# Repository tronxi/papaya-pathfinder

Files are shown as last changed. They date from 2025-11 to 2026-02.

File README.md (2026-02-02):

# Papaya Pathfinder

<div style="text-align: center;">
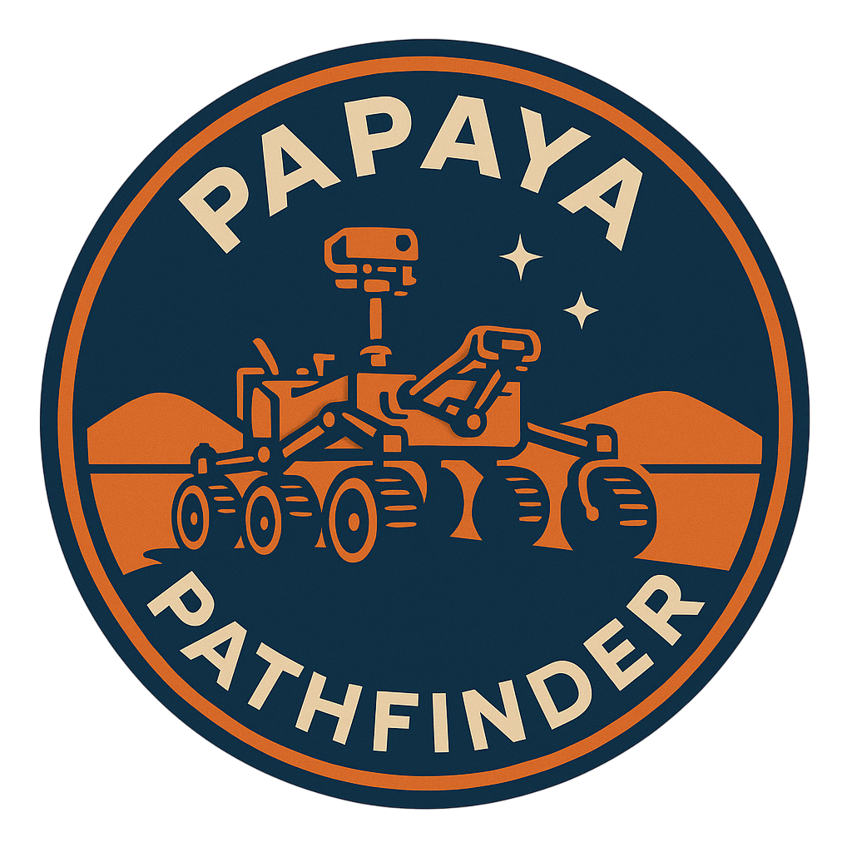
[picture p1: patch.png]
Papaya Pathfinder patch
  
</div>

Papaya Pathfinder is an open-source family of small remote-controlled rovers based on the **ESP32**.

The project currently includes **two rover variants**, designed for different sizes, motors, and power requirements.

All mechanical parts of the rovers are fully **3D-printable**, and all models are available in the `3d-models/` directories of each rover variant.

The rovers can be operated using either **WiFi** or **ExpressLRS (ELRS)**, depending on the firmware configuration.

**Watch the Papaya Pathfinder demo on YouTube**
<div align="center">
  <a href="https://www.youtube.com/watch?v=BrZb676o0gw" target="_blank">
    Papaya Pathfinder - Demo Video
  </a>
</div>

## Papaya Pathfinder

- **Controller:** ESP32
- **Radio:** ELRS receiver *(required only when running `firmware-elrs`)*
- **Motor Drivers:** 2× BTS7960 43A (or similar high-current driver)
- **Motors:** 6× GA25 DC gear motors
- **Steering:** 4× MS24 servos
- **Power:** LiPo 3S Battery
- **Voltage Regulation:**
  - 1× UBEC 5V/3A (for ESP32)
  - 1× UBEC 6V/8A (High current supply for Servos)

### Firmware
The rover supports multiple firmware configurations, each enabling a different communication method.

- **[`firmware-wifi`](pathfinder/firmware-wifi/)**
  - WiFi-based control
  - HTTP API for movement commands
  - Compatible controllers:
    - **[Python desktop controller](desktop-controller/)** — sends gamepad-based control commands to the rover via HTTP.
    - **[Android mobile app](android-controller/)** — enables rover control using a gamepad, providing the same driving experience available on the desktop controller.

- **[`firmware-elrs`](pathfinder/firmware-elrs/)**
  - Control via **ExpressLRS (ELRS)**

### 3D-Printed Parts

<div style="text-align: center;">
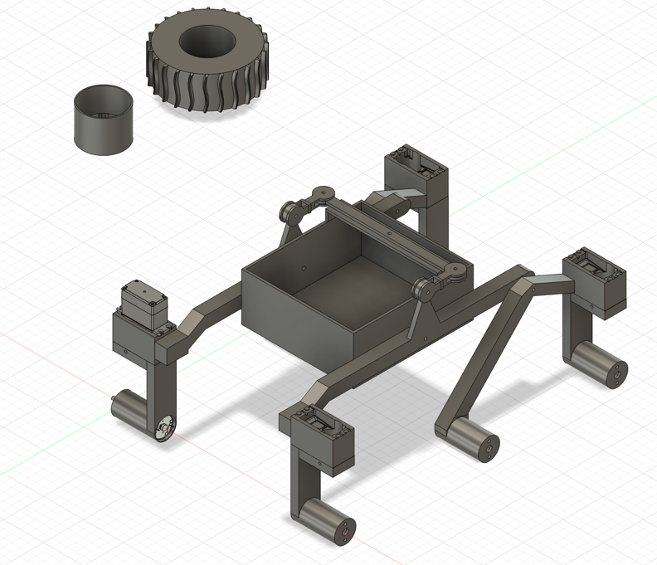
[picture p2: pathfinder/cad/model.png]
Papaya Pathfinder model
  
</div>

All STL files for this rover are available in: **[`pathfinder/3d-models/`](pathfinder/3d-models/)**

The complete mechanical design is also available in **STEP format**: **[`pathfinder/cad/papaya-pathfinder.step`](pathfinder/cad/papaya-pathfinder.step)**

Use **PETG or PLA** for the structural parts, and **TPU** for the tires. All parts are designed to be assembled using **M3 screws and nuts**.

| File | Qty | Material | Notes |
|---|-----|---|---|
| `body.stl` | 1 | PETG / PLA | Main chassis |
| `arm_left.stl` | 1 | PETG / PLA | Left suspension arm |
| `arm_right.stl` | 1 | PETG / PLA | Right suspension arm |
| `pivot_left.stl` | 1 | PETG / PLA | Left pivot mount |
| `pivot_right.stl` | 1 | PETG / PLA | Right pivot mount |
| `differential_bar.stl` | 1 | PETG / PLA | Central rocker-bogie differential bar |
| `differential_link_left.stl` | 1 | PETG / PLA | Left link between differential bar and suspension arm  |
| `differential_link_right.stl` | 1 | PETG / PLA | Right link between differential bar and suspension arm |
| `motor_mount.stl` | 4 | PETG / PLA | Motor mounts for GA25 motors used on steering arms |
| `horn_adapter.stl`  | 4 | PETG / PLA | Servo horn adapters for steering servos. **Print horizontally for strength.** |
| `rim.stl` | 6 | PETG / PLA | **Standard option.** Connects directly to the motor shaft (D-shape). Simple, but can strip over time under high torque. |
| `rim_hexagonal.stl` | 6 | PETG / PLA | **Pro option (Recommended).** Requires **12mm brass hex adapters**. Much stronger connection, prevents the motor shaft from stripping the plastic. |
| `tire.stl` | 6 | TPU | Tires |

### Wiring Diagram
- Power Distribution: Shows the rover power distribution, including the LiPo 3S battery,
  separate UBECs for logic (5V) and servos (6V), and the motor power rails.
<div style="text-align: center;">
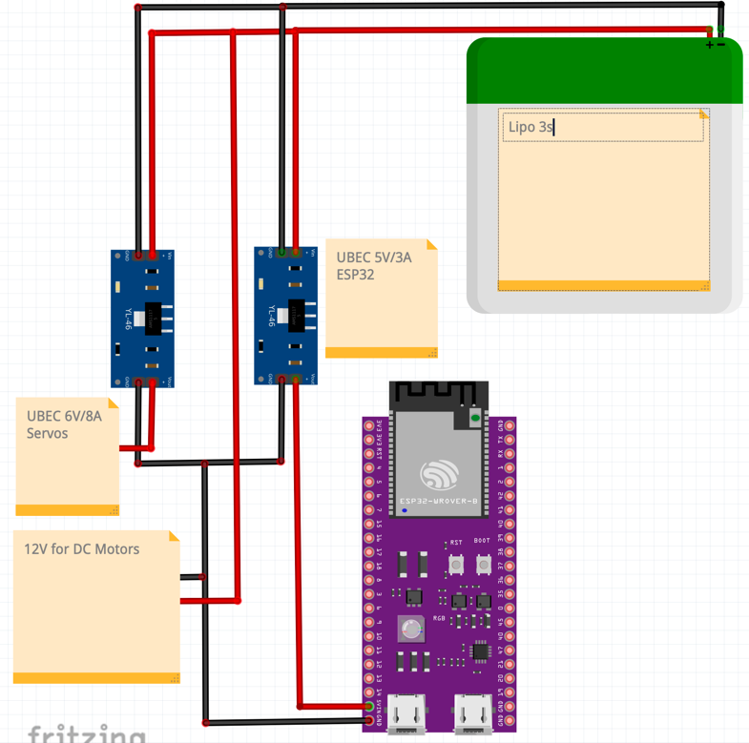
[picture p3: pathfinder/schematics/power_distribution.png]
Papaya Pathfinder power distribution
  
</div>

- Motors: Motor wiring using two BTS7960 drivers, each controlling one side of the rover.
  The ESP32 provides PWM control signals to each driver.
<div style="text-align: center;">
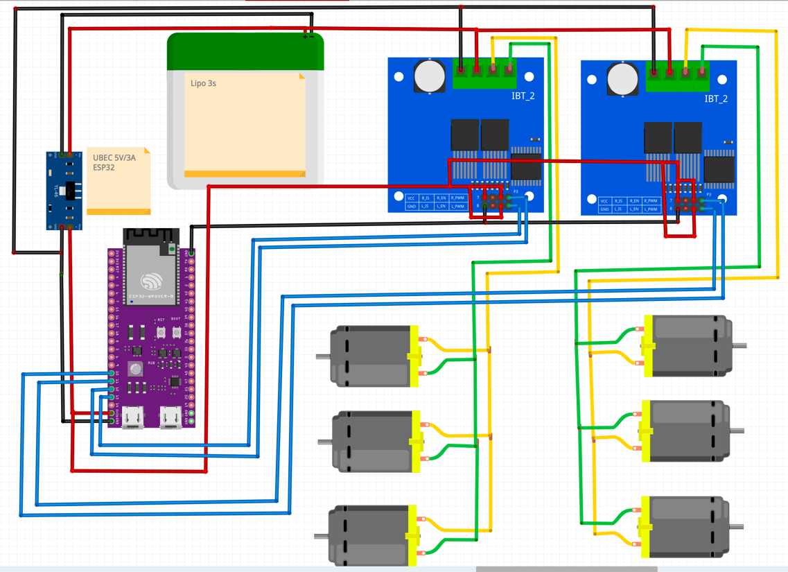
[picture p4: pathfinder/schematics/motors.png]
Papaya Pathfinder motors
  
</div>

- Servos: Servo wiring powered by a dedicated 6V UBEC. PWM control signals are provided by the ESP32.
<div style="text-align: center;">
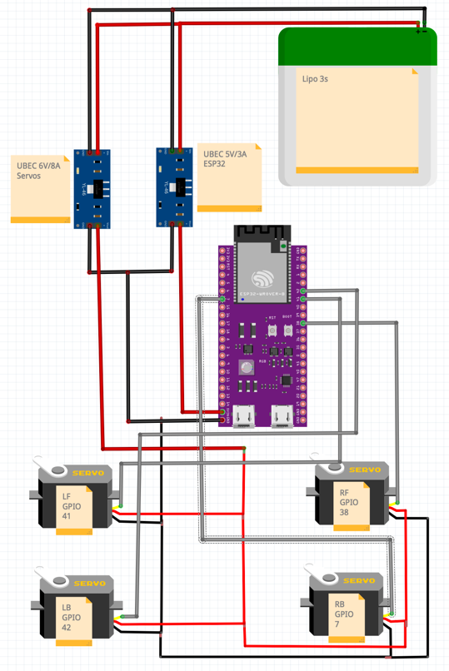
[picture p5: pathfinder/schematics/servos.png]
Papaya Pathfinder servos
  
</div>

- System Overview: High-level overview of the complete rover wiring, combining power,
  motor drivers, servos and control logic.
<div style="text-align: center;">
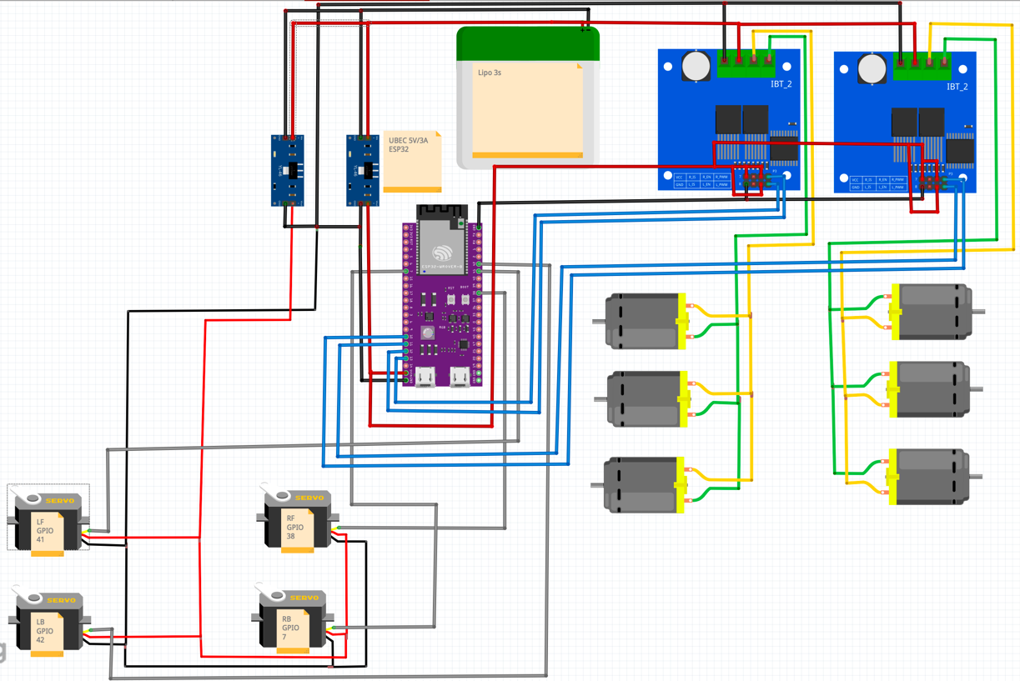
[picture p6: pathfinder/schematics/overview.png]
Papaya Pathfinder overview
  
</div>

---

## Papaya Pathfinder Mini

- **ESP32 with camera (ESP32-CAM / ESP32-S3-CAM)** *(required only when running `firmware-wifi`)*
- **ELRS receiver** *(required only when running `firmware-elrs`)*
- **6× N20 DC gear motors**
- **Power supply: LiPo 2S**
- **Voltage regulation:**
  - 1× DC-DC step-down to **5V** (ESP32 / ESP32-CAM)
  - 1× DC-DC step-down to **6V** (N20 motors)

### Firmware
The rover supports multiple firmware configurations, each enabling a different communication method.

- **[`firmware-wifi`](pathfinder-mini/firmware-wifi/)**
  - WiFi-based control
  - HTTP API for movement commands
  - Live video streaming over WiFi
  - Compatible controllers:
    - **[Python desktop controller](desktop-controller/)** — displays the live video stream and sends gamepad-based control commands to the rover via HTTP.
    - **[Android mobile app](android-controller/)** — displays the live video stream and enables rover control using a gamepad, providing the same driving experience available on the desktop controller.

- **[`firmware-elrs`](pathfinder-mini/firmware-elrs/)**
  - Control via **ExpressLRS (ELRS)**

### 3D-Printed Parts

<div style="text-align: center;">
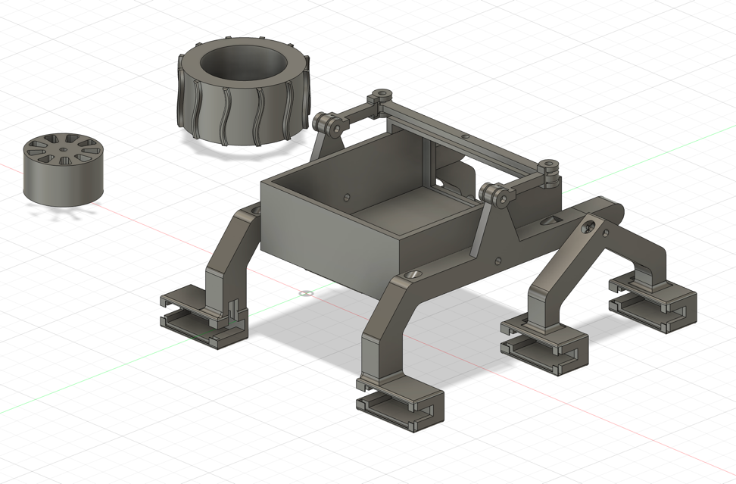
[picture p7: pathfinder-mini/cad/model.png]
Papaya Pathfinder Mini model
  
</div>

All STL files for this rover are available in: **[`pathfinder-mini/3d-models/`](pathfinder-mini/3d-models/)**

The complete mechanical design is also available in **STEP format**: **[`pathfinder-mini/cad/papaya-pathfinder-mini.step`](pathfinder-mini/cad/papaya-pathfinder-mini.step)**

Use **PETG or PLA** for the structural parts, and **TPU** for the tires. All parts are designed to be assembled using **M3 screws and nuts**.

| File | Qty | Material | Notes |
|---|-----|---|---|
| `body.stl` | 1 | PETG / PLA | Main chassis |
| `arm_left.stl` | 1 | PETG / PLA | Left suspension arm |
| `arm_right.stl` | 1 | PETG / PLA | Right suspension arm |
| `pivot_left.stl` | 1 | PETG / PLA | Left pivot mount |
| `pivot_right.stl` | 1 | PETG / PLA | Right pivot mount |
| `differential_bar.stl`  | 1 | PETG / PLA | Central differential bar for the rocker-bogie suspension |
| `differential_link.stl` | 2 | PETG / PLA | Links between the differential bar and each suspension arm |
| `motor_retainer.stl` | 6 | PETG / PLA | Holds each N20 motor |
| `rim.stl` | 6 | PETG / PLA | Wheel rims |
| `tire.stl` | 6 | TPU | Tires 

### Wiring Diagram

- System Overview: High-level overview of the complete rover wiring, combining power,
  motor drivers and control logic.
<div style="text-align: center;">
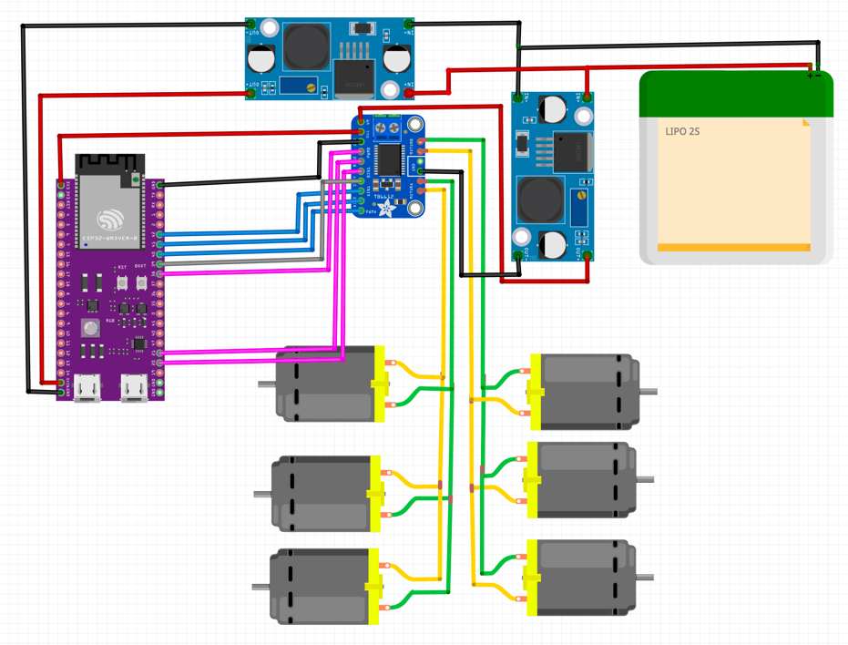
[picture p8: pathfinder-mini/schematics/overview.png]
Papaya Pathfinder Mini overview
  
</div>

## License

This project is licensed under the **Apache License 2.0**.  
See the [LICENSE](LICENSE) file for details.

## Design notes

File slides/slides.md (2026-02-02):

---
marp: true
lang: es
title: "Papaya Pathfinder: rover 3D open-source inspirado en exploración planetaria"
description: "Sergio García Sánchez"
paginate: true
size: 16:9
theme: default
class: lead
style: |
  :root { --accent: #2563eb; }
  section.lead h1, section.lead h2 { color: var(--accent); }
  section { font-size: 30px; }
  footer { color: #666; font-size: 18px; }

  .title-wrap {
    max-width: 1200px;
    margin: 0 auto;
    text-align: center;
    padding-top: 12px;
  }
  .title-wrap h1 {
    font-size: 60px;
    line-height: 1.12;
    margin: 0 0 18px 0;
    color: var(--accent);
  }
  .title-wrap .meta {
    font-size: 30px;
    line-height: 1.35;
    color: #111;
    margin: 0 0 14px 0;
  }
  .title-wrap .director {
    font-size: 26px;
    color: #333;
    margin: 0;
  }
  .title-wrap .accent {
    width: 88px;
    height: 6px;
    background: var(--accent);
    border-radius: 3px;
    margin: 20px auto 16px;
  }
  .ucm-center {
    display: block;
    margin: 18px auto 0;
    height: 92px;
    object-fit: contain;
    opacity: 0.95;
  }

  /* Utilidades opcionales */
  .muted { color:#555; }
  .two-cols { display:grid; grid-template-columns: 1fr 1fr; gap: 22px; align-items:start; }
  .img-center { display:block; margin: 0 auto; max-height: 520px; width:auto; object-fit: contain; }
header: ""
---

<!-- _class: lead -->
<div class="title-wrap">
  <h1>Papaya Pathfinder: diseño y construcción de un rover 3D open-source</h1>
  <p class="meta"><strong>Sergio García Sánchez</strong></p>
  
</div>

---

## Índice

1. **Introducción**
2. **Inspiración: rovers de exploración**
3. **Ecosistema open-source**
4. **Objetivos de Papaya Pathfinder**
5. **Sistemas de control**
6. **Papaya Pathfinder Mini**
7. **Papaya Pathfinder**
8. **Futuros pasos**
---

## 1. Introducción

Papaya Pathfinder es un **rover terrestre impreso en 3D**, inspirado en los **rovers reales de exploración de Marte**.

Se plantea como una **plataforma open-source y reproducible** para integrar mecánica, electrónica, software y comunicaciones.

---

## 2. Inspiración: rovers de exploración

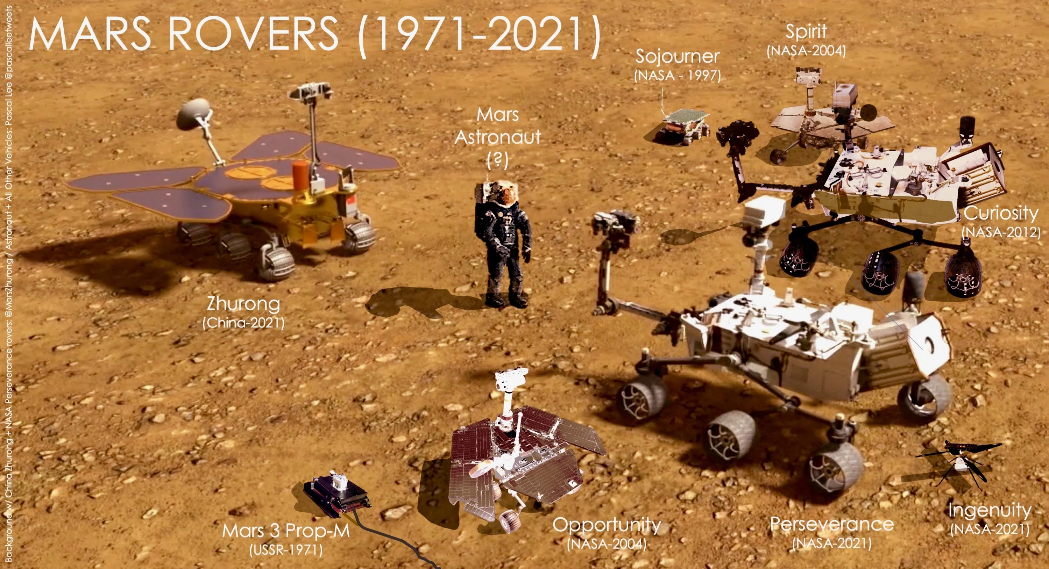
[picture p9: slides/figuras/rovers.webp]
rovers


---

<style>
.row { display: flex; gap: 24px; align-items: flex-start; }
.row .text { flex: 1; }
.row img { width: 38%; max-width: 420px; }
</style>

## 2. Inspiración: rocker-bogie

<div class="row">
  <div class="text">
    El <strong>rocker-bogie</strong> es un sistema de suspensión pasiva diseñado para rovers de exploración planetaria.
    <ul>
        <li>Un <strong>brazo principal (rocker)</strong> por cada lado</li>
        <li>Un <strong>sub-brazo (bogie)</strong> que soporta las dos ruedas traseras</li>
        <li>Un <strong>diferencial mecánico</strong> que conecta ambos lados del rover</li>
    </ul>
    Este diseño permite que <strong>las seis ruedas mantengan contacto con el suelo</strong> incluso en terrenos muy irregulares.

  </div>
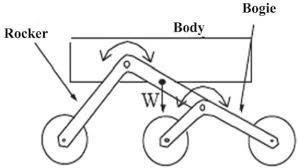
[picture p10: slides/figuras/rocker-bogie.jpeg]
rocker-bogie
  
</div>

---

## 3. Ecosistema open-source

<style>
.table-compact {
  width: 100%;
  border-collapse: collapse;
  font-size: 24px;
}
.table-compact th, .table-compact td {
  border: 1px solid #ddd;
  padding: 8px 10px;
  vertical-align: top;
}
.table-compact th {
  background: #f6f7f9;
  text-align: left;
}
.table-compact td:first-child {
  font-weight: 600;
  white-space: nowrap;
}
.note {
  margin-top: 12px;
  font-size: 22px;
  color: #555;
}
</style>

<table class="table-compact">
  <thead>
    <tr>
      <th>Proyecto</th>
      <th>Suspensión</th>
      <th>Dirección</th>
      <th>Estructura</th>
    </tr>
  </thead>
  <tbody>
    <tr>
      <td>JPL Open Source Rover</td>
      <td>Rocker-bogie</td>
      <td>Delantera y trasera</td>
      <td>Aluminio mecanizado</td>
    </tr>
    <tr>
      <td>Sawppy</td>
      <td>Rocker-bogie</td>
      <td>Delantera y trasera</td>
      <td>Aluminio + piezas impresas en 3D</td>
    </tr>
    <tr>
      <td>ExoMy</td>
      <td>Triple-bogie articulado</td>
      <td>6WS (todas las ruedas)</td>
      <td>Impresión 3D</td>
    </tr>
  </tbody>
</table>

---

## 4. Objetivos de Papaya Pathfinder

- Diseñar un **rover 100 % imprimible en 3D**, reproducible y open-source
- Utilizar una **suspensión tipo rocker-bogie**
- Incorporar **dirección en las ruedas delanteras y traseras**
- Permitir **control remoto**:
    - **WiFi**, mediante una **aplicación Android** o **scripts en Python**, con soporte de **gamepad**
    - **Radio (ELRS)** para control a mayor distancia

---

## 5. Sistemas de control por WiFi

El control del rover se realiza mediante **WiFi**, lo que permite un desarrollo rápido y flexible.

- **Control mediante gamepad**
- Dos clientes disponibles:
    - **Script en Python**
    - **Aplicación Android**
- Ambos generan los **mismos comandos HTTP**
- El rover expone una **API sencilla** para recibir órdenes de movimiento

---

## 5. Sistemas de Control: ELRS

**ExpressLRS (ELRS)** es un sistema de radiocontrol de **código abierto**, diseñado para enlaces de **largo alcance** y **control en tiempo real**.

- Basado en tecnología **LoRa (Long Range)**
- Permite alcances **muy superiores al WiFi**, dependiendo de la configuración y el entorno
- Diseñado para **baja latencia** y alta tasa de refresco en control
- No requiere **infraestructura de red** (routers o puntos de acceso)

---

## 6. Papaya Pathfinder Mini: Diseño mecánico

papaya-pathfinder-mini

---

## 6. Papaya Pathfinder Mini: Electrónica

papaya-pathfinder-mini-overview

---

## 7. Papaya Pathfinder: Diseño mecánico

Papaya Pathfinder - diseño mecánico

---

## 7. Papaya Pathfinder: Electrónica

papaya-pathfinder-overview

---

## 8. Futuros pasos

- Integrar **sensores adicionales**
- Añadir **cámaras**
- Construir una **representación simple del entorno**
- Diseñar un **brazo robótico**

---

<style>
.questions { display: grid; place-items: center; text-align: center; padding: 0 6%; }
h1 { font-size: 86px; color: var(--accent); margin: 0 0 12px; }
p.meta { font-size: 34px; color: #111; margin: 6px 0 0; }
.footer { color: #666; font-size: 28px; margin-top: 20px}
.github { font-size: 26px; margin-top: 14px; }
.github a { color: var(--accent); text-decoration: none; }
.github a:hover { text-decoration: underline; }
</style>

<div class="questions">
  <h1>Preguntas</h1>
  <p class="meta">Papaya Pathfinder: rover 3D open-source inspirado en exploración planetaria</p>
  <p class="meta">Sergio García Sánchez</p>
  <p class="github">
    GitHub: <a href="https://github.com/tronxi/papaya-pathfinder">github.com/tronxi/papaya-pathfinder</a>
  </p>
  <p class="footer">Gracias por su atención</p>
</div>

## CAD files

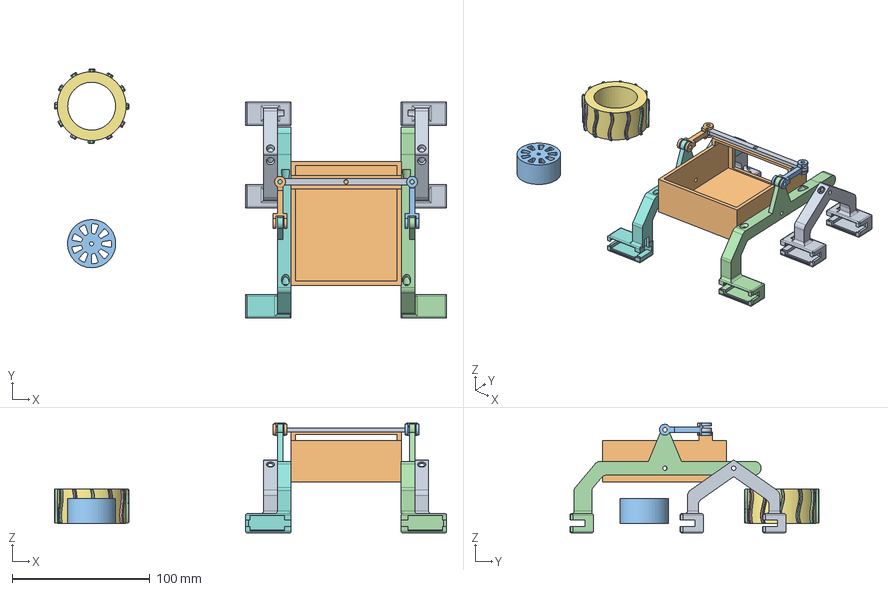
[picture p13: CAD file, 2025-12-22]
pathfinder-mini/cad/papaya-pathfinder-mini.step
285.0 x 181.0 x 79.8 mm

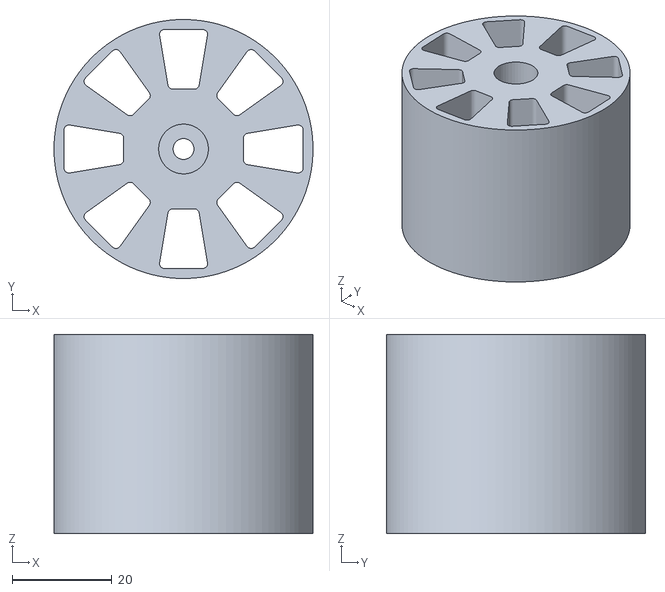
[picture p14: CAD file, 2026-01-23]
pathfinder/3d-models/rim_hexagonal.stl
52.0 x 52.0 x 40.0

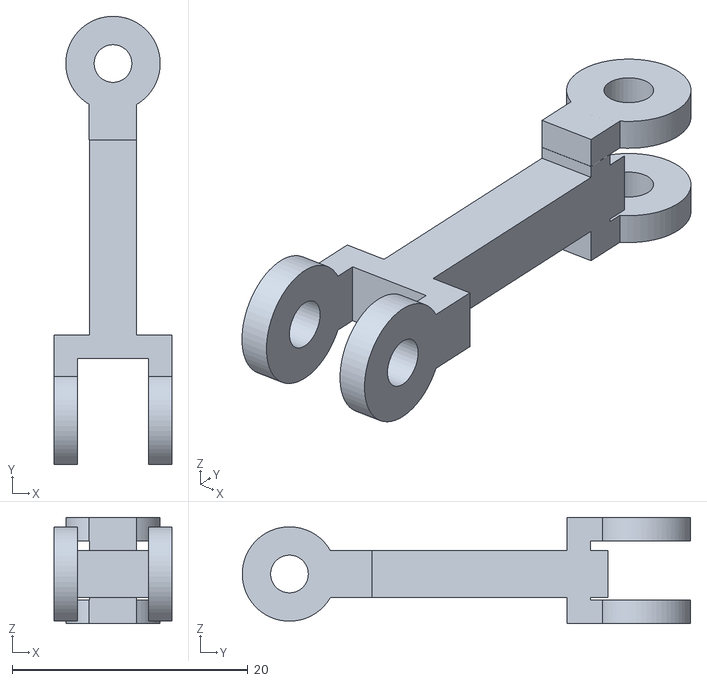
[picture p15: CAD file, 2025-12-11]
pathfinder-mini/3d-models/differencial_link.stl
10.0 x 38.0 x 9.00

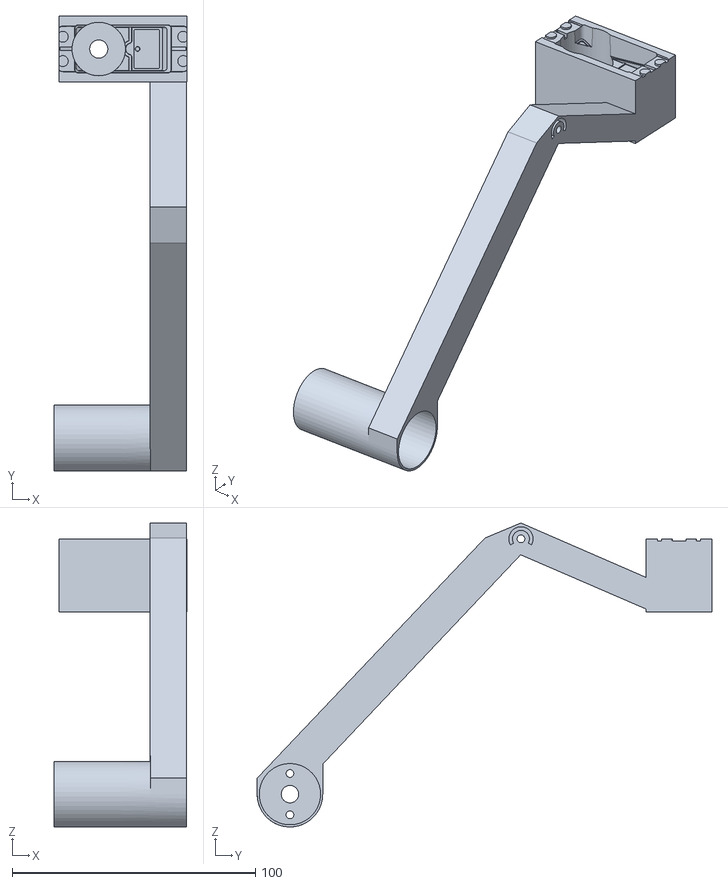
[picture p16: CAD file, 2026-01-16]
pathfinder/3d-models/pivot_right.stl
54.5 x 187.0 x 125.0

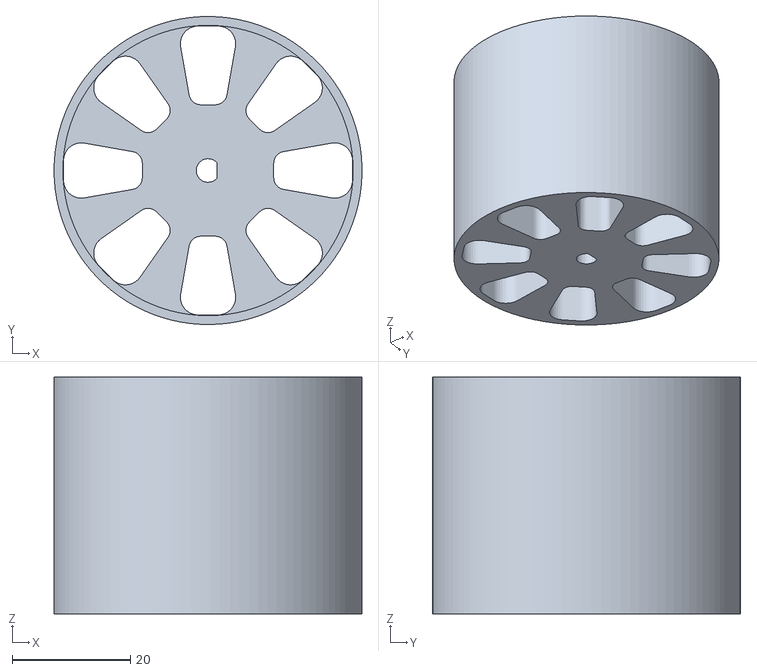
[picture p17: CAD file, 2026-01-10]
pathfinder/3d-models/rim.stl
52.0 x 52.0 x 40.0

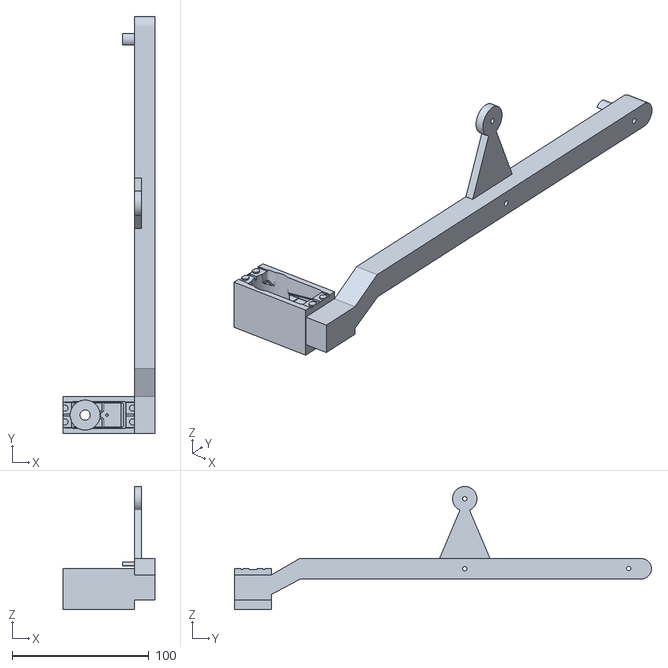
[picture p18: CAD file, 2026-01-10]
pathfinder/3d-models/arm_right.stl
67.5 x 305.2 x 90.1

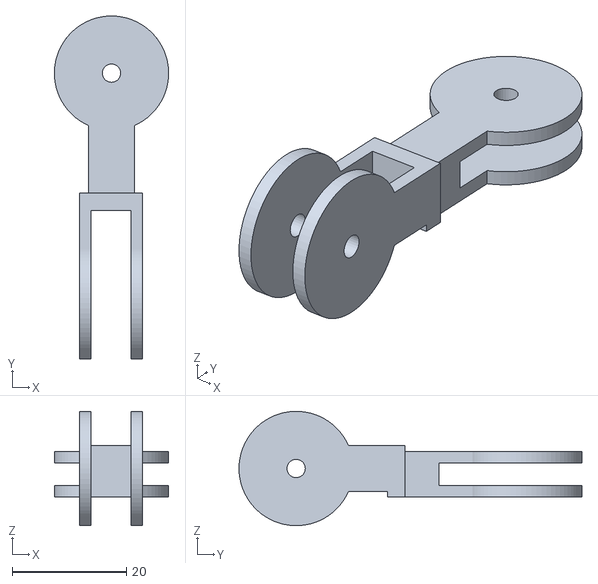
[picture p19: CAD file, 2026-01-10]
pathfinder/3d-models/differential_link_right.stl
20.0 x 60.0 x 20.0

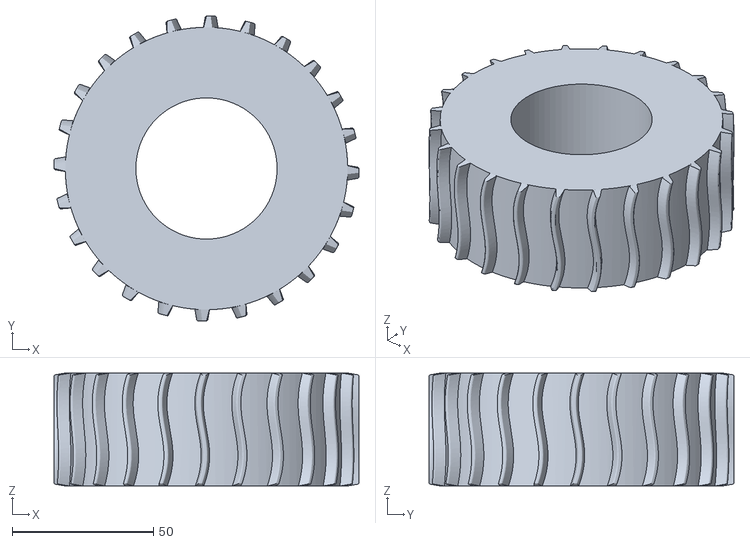
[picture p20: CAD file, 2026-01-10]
pathfinder/3d-models/tire.stl
108.0 x 108.0 x 40.0

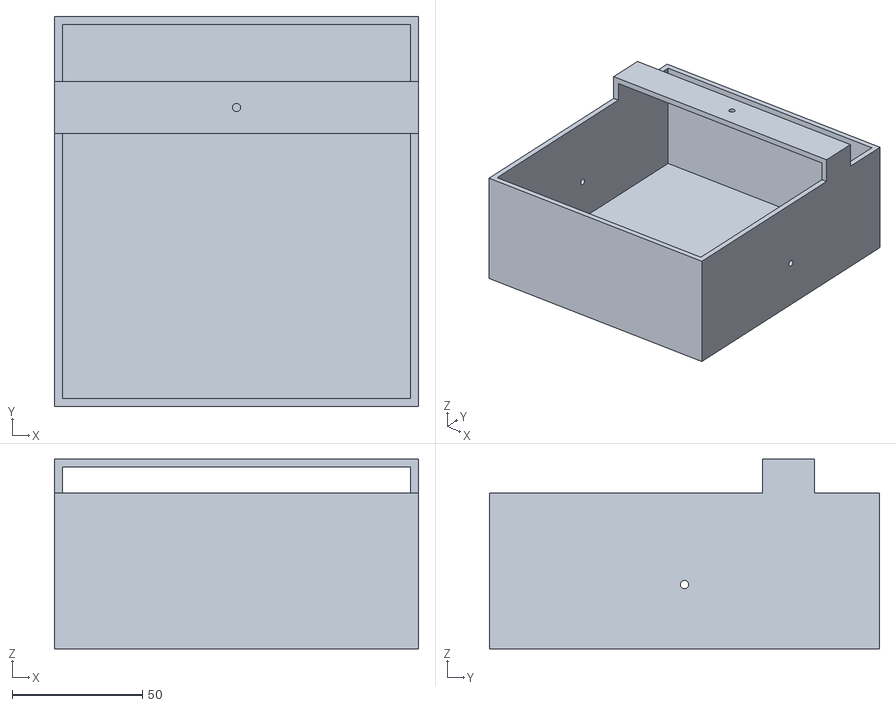
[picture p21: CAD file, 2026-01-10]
pathfinder/3d-models/body.stl
140.0 x 150.0 x 73.0

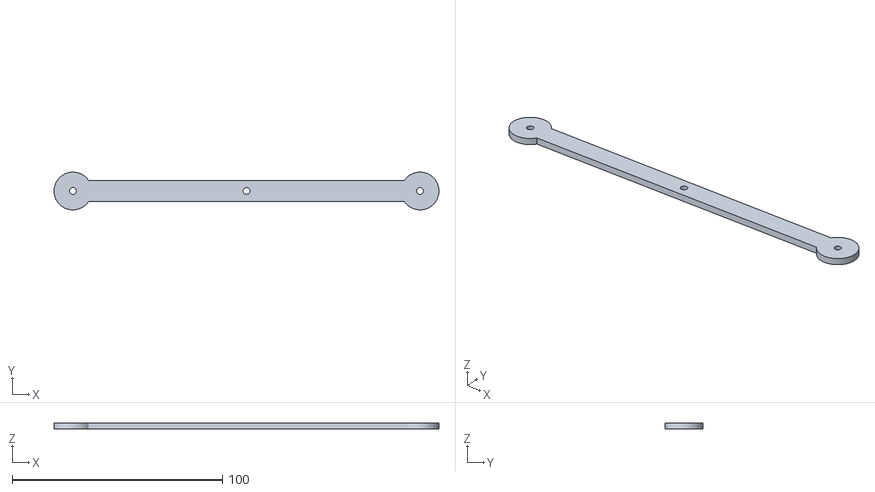
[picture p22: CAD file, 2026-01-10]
pathfinder/3d-models/differential_bar.stl
183.1 x 18.0 x 3.00

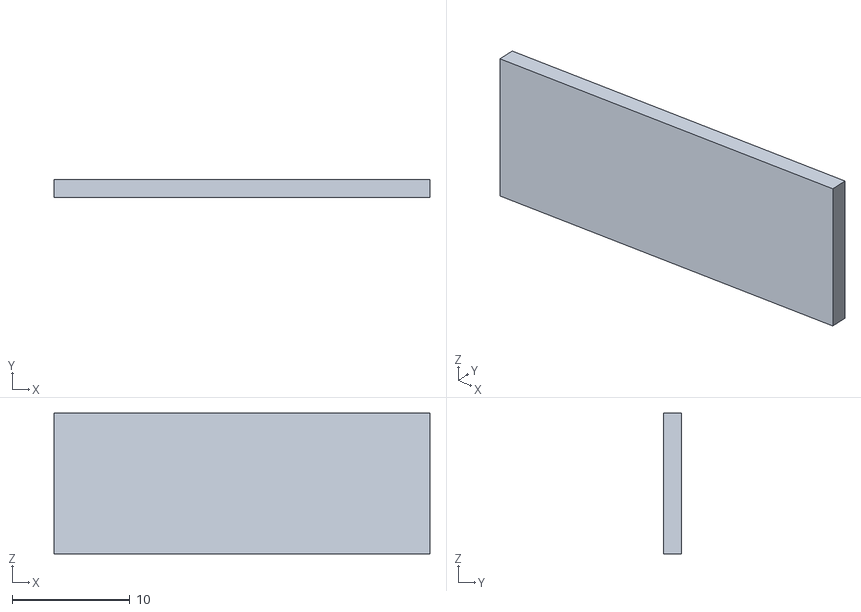
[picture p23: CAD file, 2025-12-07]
pathfinder-mini/3d-models/motor_retainer.stl
32.0 x 1.50 x 12.0

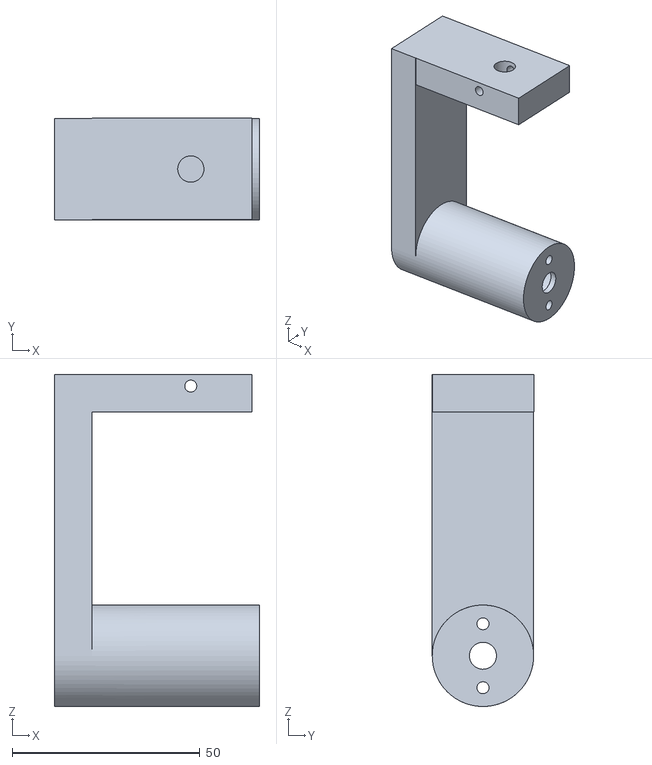
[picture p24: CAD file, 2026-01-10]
pathfinder/3d-models/motor_mount.stl
54.6 x 27.0 x 88.3

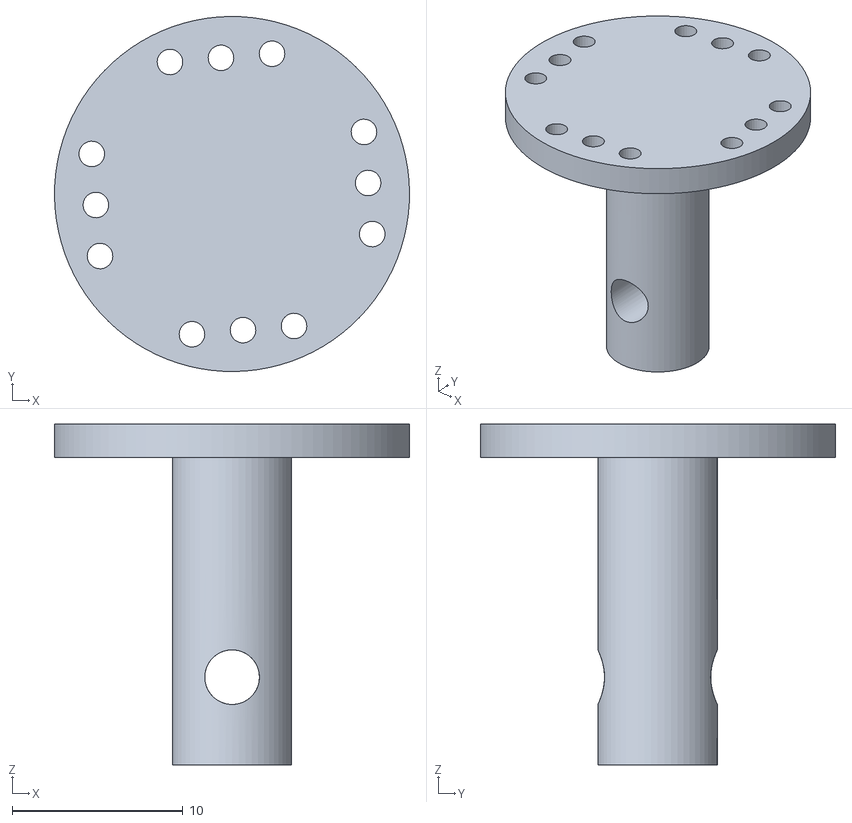
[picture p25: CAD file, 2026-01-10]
pathfinder/3d-models/horn_adapter.stl
20.8 x 20.8 x 20.0

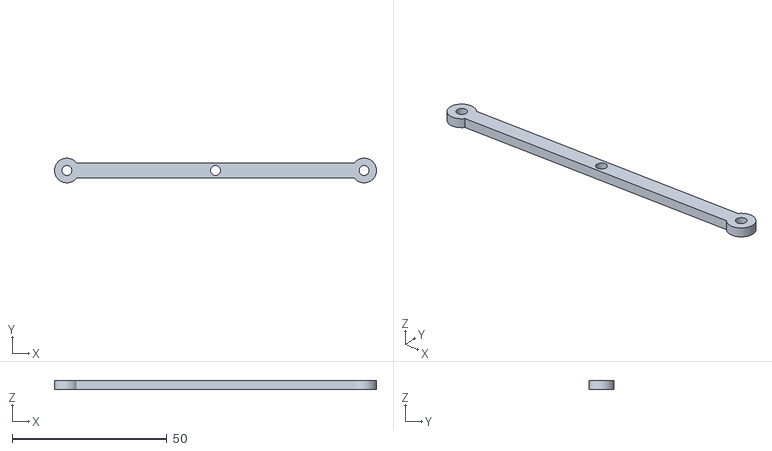
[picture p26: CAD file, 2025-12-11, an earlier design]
pathfinder-mini/3d-models/differential_bar.stl
104.0 x 8.00 x 2.80

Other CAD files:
pathfinder/3d-models/pivot_left.stl
pathfinder/3d-models/arm_left.stl
pathfinder/3d-models/differential_link_left.stl
pathfinder-mini/3d-models/arm_left.stl
pathfinder-mini/3d-models/arm_right.stl
pathfinder-mini/3d-models/body.stl
pathfinder-mini/3d-models/pivot_left.stl
pathfinder-mini/3d-models/pivot_right.stl
pathfinder-mini/3d-models/rim.stl
pathfinder-mini/3d-models/tire.stl

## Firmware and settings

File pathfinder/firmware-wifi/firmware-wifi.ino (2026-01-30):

#include <WiFi.h>
#include <Adafruit_NeoPixel.h>
#include <WebServer.h>
#include <ArduinoJson.h>
#include "wifi_config.h"

#define SERVO_RF_PIN 38
#define SERVO_RB_PIN 7
#define SERVO_LF_PIN 41
#define SERVO_LB_PIN 42

#define SERVO_FREQ 50
#define SERVO_RES 14

#define RGB_PIN 48
#define NUM_PIXELS 1

#define MOTOR_A_RPWM_PIN 12
#define MOTOR_A_LPWM_PIN 13

#define MOTOR_B_RPWM_PIN 10
#define MOTOR_B_LPWM_PIN 11

#define PWM_FREQ 10000
#define PWM_RES 8

static const int SERVO_CENTER_ANGLE = 90;
static const int SERVO_MAX_DELTA = 35;
static const int SERVO_HARDWARE_MIN = 5; 
static const int SERVO_HARDWARE_MAX = 175; 

int TRIM_LF = -10;
int TRIM_RF = 0;
int TRIM_LB = -5;
int TRIM_RB = -3;

WebServer server(8080);
Adafruit_NeoPixel rgb(NUM_PIXELS, RGB_PIN, NEO_GRB + NEO_KHZ800);

bool connectToWiFi(const char* ssid, const char* pass, uint32_t timeoutMs);
void handlePostData();
void setSteering(float steer);
void setMotor(float throttle);
void writeServo(int pin, int angle);
void setSpin(float spinVal);
void led(int r, int g, int b);

void setup() {
  Serial.begin(115200);
  Serial.setDebugOutput(true);
  rgb.begin();
  rgb.show();

  led(255, 255, 255);

  ledcAttach(MOTOR_A_RPWM_PIN, PWM_FREQ, PWM_RES);
  ledcAttach(MOTOR_A_LPWM_PIN, PWM_FREQ, PWM_RES);
  ledcWrite(MOTOR_A_RPWM_PIN, 0);
  ledcWrite(MOTOR_A_LPWM_PIN, 0);

  ledcAttach(MOTOR_B_RPWM_PIN, PWM_FREQ, PWM_RES);
  ledcAttach(MOTOR_B_LPWM_PIN, PWM_FREQ, PWM_RES);
  ledcWrite(MOTOR_B_RPWM_PIN, 0);
  ledcWrite(MOTOR_B_LPWM_PIN, 0);

  ledcAttach(SERVO_RF_PIN, SERVO_FREQ, SERVO_RES);
  ledcAttach(SERVO_RB_PIN, SERVO_FREQ, SERVO_RES);
  ledcAttach(SERVO_LF_PIN, SERVO_FREQ, SERVO_RES);
  ledcAttach(SERVO_LB_PIN, SERVO_FREQ, SERVO_RES);

  setSteering(0.0f);

  bool connected = false;

  Serial.print("Attempting WiFi 1: ");
  Serial.println(WIFI_SSID_1);

  if (connectToWiFi(WIFI_SSID_1, WIFI_PASSWORD_1, 10000)) {
    Serial.println("Connected to WiFi 1");
    led(0, 0, 255);
    connected = true;
  }

  if (!connected) {
    Serial.println("WiFi 1 failed. Waiting to try WiFi 2...");
    delay(1000);

    Serial.print("Attempting WiFi 2: ");
    Serial.println(WIFI_SSID_2);

    if (connectToWiFi(WIFI_SSID_2, WIFI_PASSWORD_2, 10000)) {
      Serial.println("Connected to WiFi 2");
      led(0, 255, 0);
      connected = true;
    }
  }

  if (!connected) {
    Serial.println("ERROR: Could not connect to any WiFi network.");
    led(255, 0, 0);
  }

  Serial.print(WiFi.localIP());
  Serial.println("' to connect");

  server.on("/controller", HTTP_POST, handlePostData);
  server.begin();

  Serial.println("Ready");
}

void loop() {
  server.handleClient();
}

bool connectToWiFi(const char* ssid, const char* pass, uint32_t timeoutMs) {
  WiFi.disconnect(true);
  WiFi.mode(WIFI_OFF);
  delay(200);

  WiFi.mode(WIFI_STA);
  WiFi.begin(ssid, pass);
  WiFi.setSleep(false);

  Serial.print("Connecting to ");
  Serial.print(ssid);

  uint32_t start = millis();
  while (WiFi.status() != WL_CONNECTED && millis() - start < timeoutMs) {
    delay(500);
    Serial.print(".");
  }
  Serial.println();

  return WiFi.status() == WL_CONNECTED;
}

void handlePostData() {
  if (!server.hasArg("plain")) {
    server.send(400, "text/plain", "Missing body");
    return;
  }

  String json = server.arg("plain");
  Serial.println(json);

  StaticJsonDocument<1024> doc;

  DeserializationError err = deserializeJson(doc, json);
  if (err) {
    Serial.print("JSON parse error: ");
    Serial.println(err.c_str());
    server.send(400, "text/plain", "Bad JSON");
    return;
  }

  float steeringVal = doc["axes"][2];
  float throttleVal = doc["axes"][1];
  float spinVal = doc["axes"][0];

float deadzone = 0.1;

  if (abs(spinVal) > deadzone && abs(throttleVal) < deadzone && abs(steeringVal) < deadzone) {
        setSpin(spinVal);
  } else {
    setSteering(steeringVal);
    setMotor(throttleVal);
  }

  server.send(200, "application/json", "{\"status\":\"ok\"}");
}

void writeServo(int pin, int angle) {
  angle = constrain(angle, SERVO_HARDWARE_MIN, SERVO_HARDWARE_MAX);
  int duty = map(angle, 0, 180, 410, 1966);

  ledcWrite(pin, duty);
}

void setSteering(float steer) {
  steer = constrain(steer, -1.0f, 1.0f);
  int delta = steer * SERVO_MAX_DELTA;

  int lf_angle = SERVO_CENTER_ANGLE + TRIM_LF + delta;
  int rf_angle = SERVO_CENTER_ANGLE + TRIM_RF + delta;
  int lb_angle = SERVO_CENTER_ANGLE + TRIM_LB - delta;
  int rb_angle = SERVO_CENTER_ANGLE + TRIM_RB - delta;

  writeServo(SERVO_LF_PIN, lf_angle);
  writeServo(SERVO_RF_PIN, rf_angle);
  writeServo(SERVO_LB_PIN, lb_angle);
  writeServo(SERVO_RB_PIN, rb_angle);
}

void setMotor(float throttle) {
  throttle = constrain(throttle, -1.0f, 1.0f);

  int pwmValue = abs(throttle) * 255;

  if (throttle > 0.05) {
    ledcWrite(MOTOR_A_RPWM_PIN, 0);
    ledcWrite(MOTOR_A_LPWM_PIN, pwmValue);

    ledcWrite(MOTOR_B_RPWM_PIN, pwmValue);
    ledcWrite(MOTOR_B_LPWM_PIN, 0);
  } else if (throttle < -0.05) {
    ledcWrite(MOTOR_A_RPWM_PIN, pwmValue);
    ledcWrite(MOTOR_A_LPWM_PIN, 0);

    ledcWrite(MOTOR_B_RPWM_PIN, 0);
    ledcWrite(MOTOR_B_LPWM_PIN, pwmValue);
  } else {
    ledcWrite(MOTOR_A_RPWM_PIN, 0);
    ledcWrite(MOTOR_A_LPWM_PIN, 0);

    ledcWrite(MOTOR_B_RPWM_PIN, 0);
    ledcWrite(MOTOR_B_LPWM_PIN, 0);
  }
}

void setSpin(float spinVal) {
  spinVal = constrain(spinVal, -1.0f, 1.0f);
  
  int angle = 45;

  int lf = SERVO_CENTER_ANGLE + TRIM_LF + angle;
  int rf = SERVO_CENTER_ANGLE + TRIM_RF - angle;
  int lb = SERVO_CENTER_ANGLE + TRIM_LB - angle;
  int rb = SERVO_CENTER_ANGLE + TRIM_RB + angle;

  writeServo(SERVO_LF_PIN, lf);
  writeServo(SERVO_RF_PIN, rf);
  writeServo(SERVO_LB_PIN, lb);
  writeServo(SERVO_RB_PIN, rb);

  int pwm = abs(spinVal) * 255;

  if (spinVal < 0) {
    ledcWrite(MOTOR_A_RPWM_PIN, 0);
    ledcWrite(MOTOR_A_LPWM_PIN, pwm);
    
    ledcWrite(MOTOR_B_RPWM_PIN, 0);
    ledcWrite(MOTOR_B_LPWM_PIN, pwm);
    
  } else {
    ledcWrite(MOTOR_A_RPWM_PIN, pwm);
    ledcWrite(MOTOR_A_LPWM_PIN, 0);
    ledcWrite(MOTOR_B_RPWM_PIN, pwm);
    ledcWrite(MOTOR_B_LPWM_PIN, 0);
  }
}

void led(int r, int g, int b) {
  rgb.setPixelColor(0, rgb.Color(r, g, b));
  rgb.show();
}

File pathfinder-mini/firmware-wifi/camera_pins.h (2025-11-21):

#ifndef CAMERA_PINS_H
#define CAMERA_PINS_H

#if defined(CAMERA_MODEL_ESP32_S3_N16R8_CAM)

#define PWDN_GPIO_NUM  -1
#define RESET_GPIO_NUM -1
#define XCLK_GPIO_NUM  15
#define SIOD_GPIO_NUM  4
#define SIOC_GPIO_NUM  5

#define Y2_GPIO_NUM    11
#define Y3_GPIO_NUM    9
#define Y4_GPIO_NUM    8
#define Y5_GPIO_NUM    10
#define Y6_GPIO_NUM    12
#define Y7_GPIO_NUM    18
#define Y8_GPIO_NUM    17
#define Y9_GPIO_NUM    16

#define VSYNC_GPIO_NUM 6
#define HREF_GPIO_NUM  7
#define PCLK_GPIO_NUM  13

#else
#error "Camera model not selected or not supported in this camera_pins.h"
#endif

#endif // CAMERA_PINS_H

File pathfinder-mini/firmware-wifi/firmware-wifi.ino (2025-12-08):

#include "esp_camera.h"
#include <WiFi.h>
#include <Adafruit_NeoPixel.h>
#include <WebServer.h>
#include <ArduinoJson.h>

#include "board_config.h"
#include "wifi_config.h"

void startCameraServer();

#define RGB_PIN 48
#define NUM_PIXELS  1

#define PWMA 41
#define AIN1 40
#define AIN2 42
#define PWMB 38
#define BIN1 20
#define BIN2 21
#define STBY 39


Adafruit_NeoPixel rgb(NUM_PIXELS, RGB_PIN, NEO_GRB + NEO_KHZ800);
WebServer server(8080); 

void setup() {
  Serial.begin(115200);
  Serial.setDebugOutput(true);
  rgb.begin();
  rgb.show();

  rgb.setPixelColor(0, rgb.Color(255, 255, 255));
  rgb.show();

  pinMode(AIN1, OUTPUT);
  pinMode(AIN2, OUTPUT);
  pinMode(BIN1, OUTPUT);
  pinMode(BIN2, OUTPUT);
  pinMode(STBY, OUTPUT);

  analogWriteFrequency(PWMA, 20000);
  analogWriteResolution(PWMA, 8);
  analogWriteFrequency(PWMB, 20000);
  analogWriteResolution(PWMB, 8);

  digitalWrite(STBY, HIGH);

  stopMotorA();
  stopMotorB();


  camera_config_t config;
  config.ledc_channel = LEDC_CHANNEL_1;
  config.ledc_timer   = LEDC_TIMER_1;

  config.pin_d0       = Y2_GPIO_NUM;
  config.pin_d1       = Y3_GPIO_NUM;
  config.pin_d2       = Y4_GPIO_NUM;
  config.pin_d3       = Y5_GPIO_NUM;
  config.pin_d4       = Y6_GPIO_NUM;
  config.pin_d5       = Y7_GPIO_NUM;
  config.pin_d6       = Y8_GPIO_NUM;
  config.pin_d7       = Y9_GPIO_NUM;

  config.pin_xclk     = XCLK_GPIO_NUM;
  config.pin_pclk     = PCLK_GPIO_NUM;
  config.pin_vsync    = VSYNC_GPIO_NUM;
  config.pin_href     = HREF_GPIO_NUM;
  config.pin_sccb_sda = SIOD_GPIO_NUM;
  config.pin_sccb_scl = SIOC_GPIO_NUM;
  config.pin_pwdn     = PWDN_GPIO_NUM;
  config.pin_reset    = RESET_GPIO_NUM;

  config.xclk_freq_hz = 20000000;
  config.pixel_format = PIXFORMAT_JPEG;

  bool has_psram = psramFound();
  Serial.printf("PSRAM: %s\n", has_psram ? "YES" : "NO");

  if (has_psram) {
    config.pixel_format = PIXFORMAT_JPEG;
    config.frame_size   = FRAMESIZE_SVGA;
    config.jpeg_quality = 25;
    config.fb_count     = 1;
    config.fb_location  = CAMERA_FB_IN_PSRAM;
    config.grab_mode    = CAMERA_GRAB_LATEST;
  } else {
    config.frame_size   = FRAMESIZE_QVGA;
    config.jpeg_quality = 16;
    config.fb_count     = 1;
    config.fb_location  = CAMERA_FB_IN_DRAM;
  }

  config.grab_mode    = CAMERA_GRAB_LATEST;

  esp_err_t err = esp_camera_init(&config);
  if (err != ESP_OK) {
    Serial.printf("Camera init failed with error 0x%x\n", err);
    return;
  }

  sensor_t *s = esp_camera_sensor_get();
  if (s && s->id.PID == OV3660_PID) {
    s->set_vflip(s, 1);
    s->set_brightness(s, 1);
    s->set_saturation(s, -2);
  }

  bool connected = false;

  Serial.print("Attempting WiFi 1: ");
  Serial.println(WIFI_SSID_1);
  
  if (connectToWiFi(WIFI_SSID_1, WIFI_PASSWORD_1, 10000)) {
    Serial.println("Connected to WiFi 1");
    led(0, 0, 255);
    connected = true;
  } 
  
  if (!connected) {
    Serial.println("WiFi 1 failed. Waiting to try WiFi 2...");
    delay(1000); 
    
    Serial.print("Attempting WiFi 2: ");
    Serial.println(WIFI_SSID_2);
    
    if (connectToWiFi(WIFI_SSID_2, WIFI_PASSWORD_2, 10000)) {
      Serial.println("Connected to WiFi 2");
      led(0, 255, 0);
      connected = true;
    }
  }

  if (!connected) {
    Serial.println("ERROR: Could not connect to any WiFi network.");
    led(255, 0, 0);
  }

  startCameraServer();

  Serial.print("Camera Ready! Use 'http://");
  Serial.print(WiFi.localIP());
  Serial.println("' to connect");

  server.on("/controller", HTTP_POST, handlePostData);
  server.begin();


  Serial.println("Ready");
}

void loop() {
  server.handleClient();
}

bool connectToWiFi(const char* ssid, const char* pass, uint32_t timeoutMs) {
    WiFi.disconnect(true); 
    WiFi.mode(WIFI_OFF);   
    delay(200);            

    WiFi.mode(WIFI_STA);
    WiFi.begin(ssid, pass);
    WiFi.setSleep(false);   

    Serial.print("Connecting to ");
    Serial.print(ssid);

    uint32_t start = millis();
    while (WiFi.status() != WL_CONNECTED && millis() - start < timeoutMs) {
        delay(500);
        Serial.print(".");
    }
    Serial.println();

    return WiFi.status() == WL_CONNECTED;
}

void handlePostData() {
  if (!server.hasArg("plain")) {
    server.send(400, "text/plain", "Missing body");
    return;
  }

  String json = server.arg("plain");

  StaticJsonDocument<1024> doc;

  DeserializationError err = deserializeJson(doc, json);
  if (err) {
    Serial.print("JSON parse error: ");
    Serial.println(err.c_str());
    server.send(400, "text/plain", "Bad JSON");
    return;
  }

  float right = doc["axes"][3];
  uint8_t speed = abs(right) * 255;
  if (speed > 253) speed = 255;
  if (right > 0) {
    startMotorB(speed, 1);
  } else if (right < 0) {
    startMotorB(speed, 0);
  } else {
    stopMotorB();
  }

  float left = doc["axes"][1];
  uint8_t speedLeft = abs(left) * 255;
  if (speedLeft > 253) speedLeft = 255;
  if (left > 0) {
    startMotorA(speedLeft, 1);

  } else if (left < 0) {
    startMotorA(speedLeft, 0);
  } else {
    stopMotorA();
  }

  server.send(200, "application/json", "{\"status\":\"ok\"}");
}

void led(int r, int g, int b) {
  rgb.setPixelColor(0, rgb.Color(r, g, b));
  rgb.show();
}

void startMotorA(uint8_t speed, uint8_t direction) {

  if (direction == 1) {
    digitalWrite(AIN1, HIGH);
    digitalWrite(AIN2, LOW);
  } else {
    digitalWrite(AIN1, LOW);
    digitalWrite(AIN2, HIGH);
  }

  analogWrite(PWMA, speed);
}

void startMotorB(uint8_t speed, uint8_t direction) {

  if (direction == 1) {
    digitalWrite(BIN1, HIGH);
    digitalWrite(BIN2, LOW);
  } else {
    digitalWrite(BIN1, LOW);
    digitalWrite(BIN2, HIGH);
  }

  analogWrite(PWMB, speed);
}

void stopMotorA() {
  digitalWrite(AIN1, LOW);
  digitalWrite(AIN2, LOW);
  analogWrite(PWMA, 0);
}

void stopMotorB() {
  digitalWrite(BIN1, LOW);
  digitalWrite(BIN2, LOW);
  analogWrite(PWMB, 0);
}

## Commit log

2025-11-21 camera and controller
2025-11-24 fix motor pin
2025-12-06 add wheel files
    [rin.stl, tire.stl]
2025-12-07 add 3d models
    [arm_left.stl, arm_right.stl, body.stl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]
2025-12-08 update models
    [rim_v2.stl, tire_v2.stl]
2025-12-08 show devices and change icon
2025-12-08 add .cad
    [papaya-pathfinder.step]
2025-12-12 add photo
    [papaya-pathfinder-v2.step]
2025-12-22 add pathfinder-mini
    [arm_left.stl, arm_right.stl, body.stl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]
2025-12-22 update cad
    [papaya-pathfinder-mini.step]
2026-01-10 add firmware erls for pathfinder mini
    [partitions.csv]
2026-01-10 add cad and 3d models for papaya pathfinder
    [arm_left.stl, arm_right.stl, body.stl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]
2026-01-16 update patfhinder models
    [pivot_left.stl, pivot_right.stl]
2026-01-22 change servo pin
2026-01-23 add hexagonal rim
    [rim_hexagonal.stl]
2026-01-30 add wiring diagram
    [schematics.fzz]
2026-01-30 update doc
    [schematics.fzz]
2026-01-30 add schematics
    [schematics.fzz]
2026-02-02 add pathfinder mini overview
    [schematics-mini.fzz]
